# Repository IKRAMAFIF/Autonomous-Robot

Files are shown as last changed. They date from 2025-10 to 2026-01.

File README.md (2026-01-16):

# 🤖 Projet CATRONIC : Robot Autonome "Chat et Souris"

<p align="center">
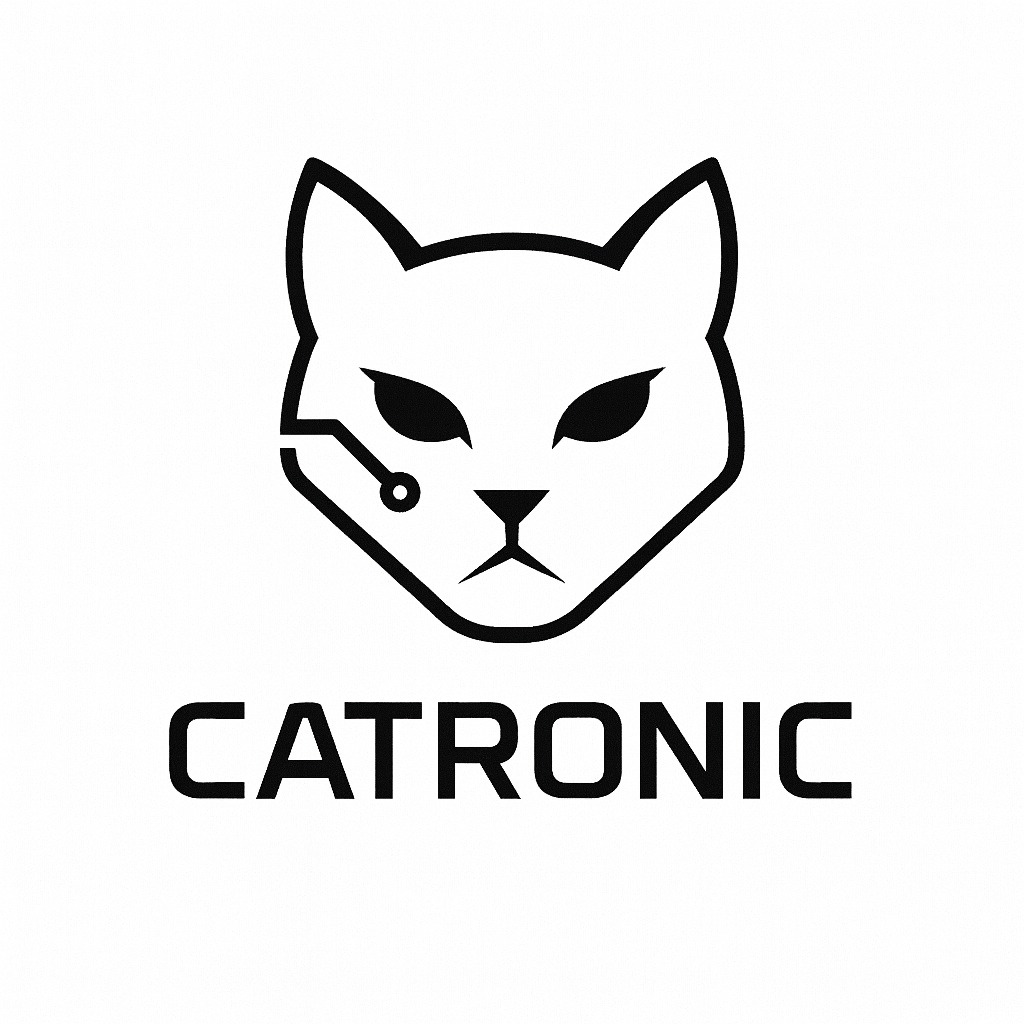
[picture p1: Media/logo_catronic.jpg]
Logo Catronic
  
</p>

> **Auteurs :** AFIF Ikram, AIT ALLA Hajar, MENJLI Fakhri

> **Encadré par :** Laurent FIACK, Nicolas PAPAZOGLOU

> **Année académique :** 2025/2026

Le robot **CATRONIC** est un système embarqué autonome conçu pour simuler un jeu de chat et de souris entre plusieurs robots identiques. Les robots évoluent sur une table sans bordures et sont capables de détecter les bords pour éviter toute chute.

---

##  Table des matières
- [Stratégie de fonctionnement](#stratégie-de-fonctionnement)
- [Architecture du système](#architecture-du-système-global)
  - [Schémas généraux](#schémas-généraux)
  - [Sous-systèmes](#sous-systèmes)
- [Nomenclature (Bill of Materials)](#nomenclature-bill-of-materials)
- [Structure logicielle et FreeRTOS](#structure-logicielle-et-freertos)
- [Tests et validation](#tests-et-validation)
- [Test final](#test-final)
- [Conclusion](#conclusion)

---

##  Stratégie de fonctionnement

La logique du robot est orchestrée par un noyau temps réel (**FreeRTOS**), permettant de gérer plusieurs tâches simultanément pour une réactivité maximale.

### Détection de l'environnement

- **Détection des bords :** Le robot utilise des **capteurs mécaniques Würth WS-MITV** positionnés à l’avant, à l’arrière, à gauche et à droite. Lorsqu’un capteur détecte le vide, il déclenche une interruption qui ordonne un changement immédiat de direction pour éviter la chute.  
- **Détection des adversaires :** Le **LIDAR YDLIDAR X2** scanne l’environnement à 360° et transmet en temps réel la position et la distance des autres robots.  
- **Détection des collisions :** L’**accéléromètre ADXL343** détecte les chocs par variation brutale d’accélération. Il est également utilisé comme arrêt d’urgence manuel.

### Modes de jeu

- **Mode Souris 🐭 :** Le robot cherche à maximiser la distance avec le “chat” tout en évitant les bords de la table.  
- **Mode Chat 🐱 :** Le robot identifie la “souris” la plus proche via le LIDAR et cherche à la percuter.

---

##  Architecture du système global

L’architecture est organisée autour de cinq sous-ensembles principaux : **alimentation**, **commande**, **acquisition**, **déplacement** et **interface utilisateur**.

### Schémas généraux

Vues d’ensemble de l’architecture matérielle :

**Figure 1 – Diagramme d’architecture fonctionnelle du robot:**

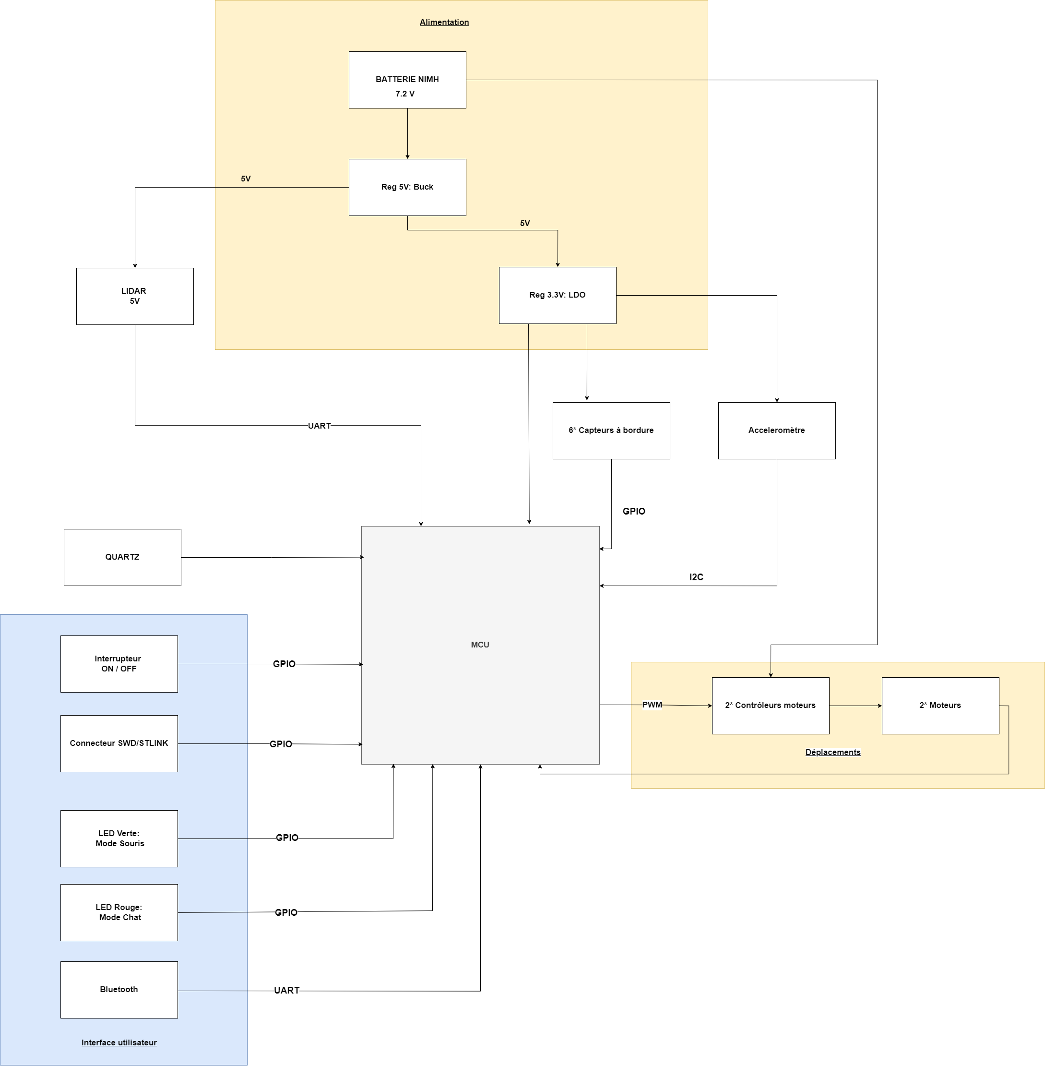
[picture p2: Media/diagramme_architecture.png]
Diagramme d'architecture


**Figure 2 – Schéma global du système:**

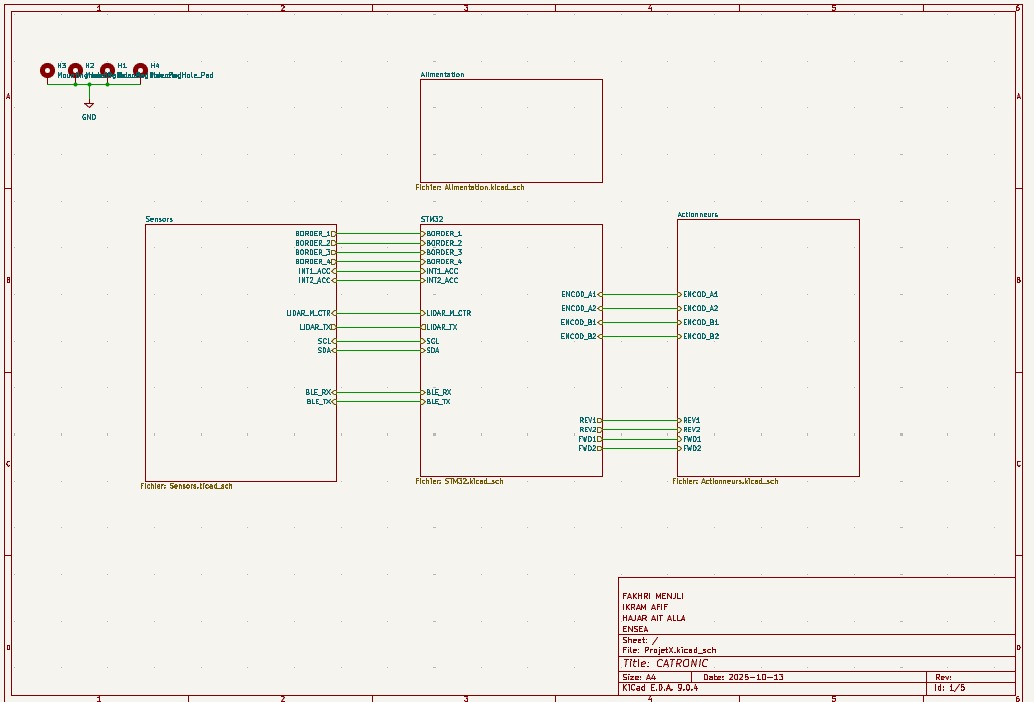
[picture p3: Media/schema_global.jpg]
Schéma global


**Figure 3 – Routage du PCB principal:**

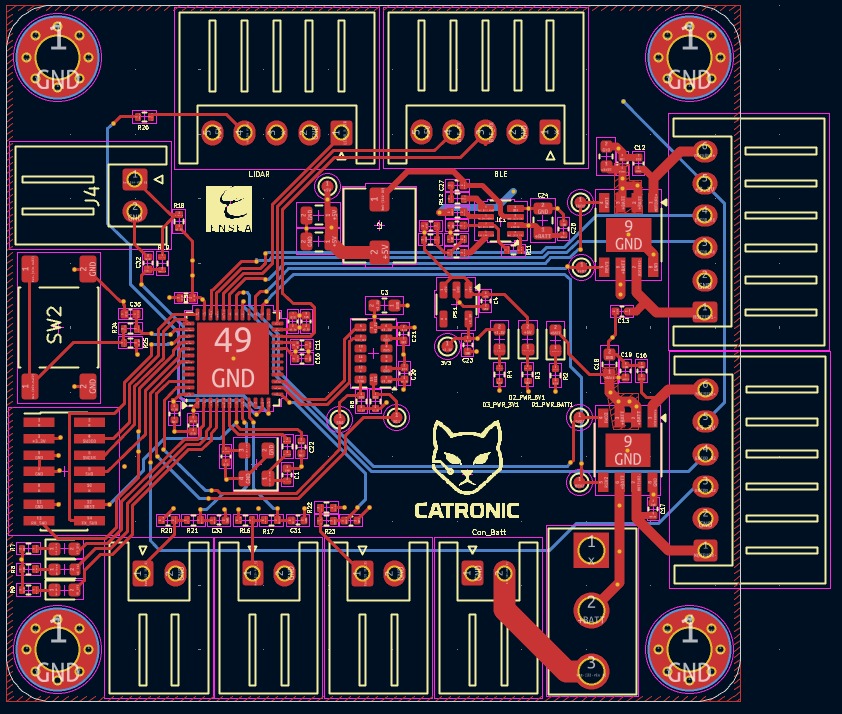
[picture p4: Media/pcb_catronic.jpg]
PCB Catronic


**Figure 4 – Vue 3D du PCB sous KiCad:**

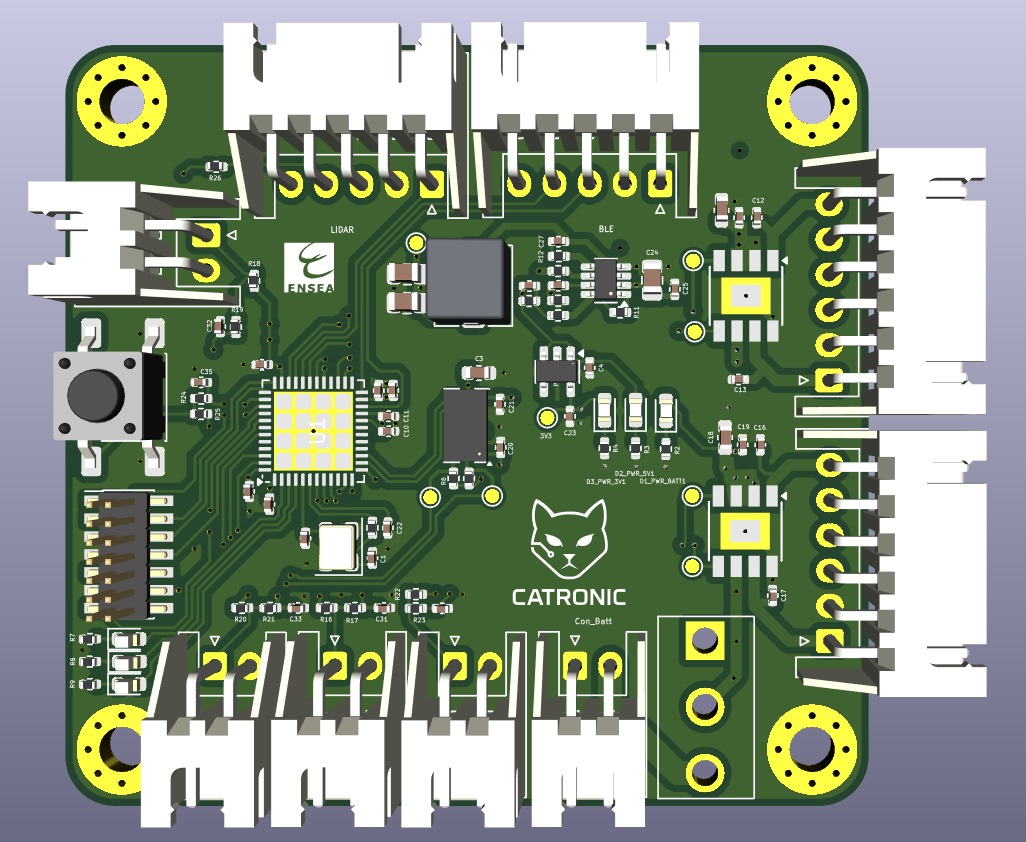
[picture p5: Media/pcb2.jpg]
Vue 3D du PCB


### Sous-systèmes

####  Alimentation
Le robot est alimenté par une batterie **NiMH 7.2V**, régulée en **5V** pour le LIDAR et en **3.3V** pour le reste des composants.

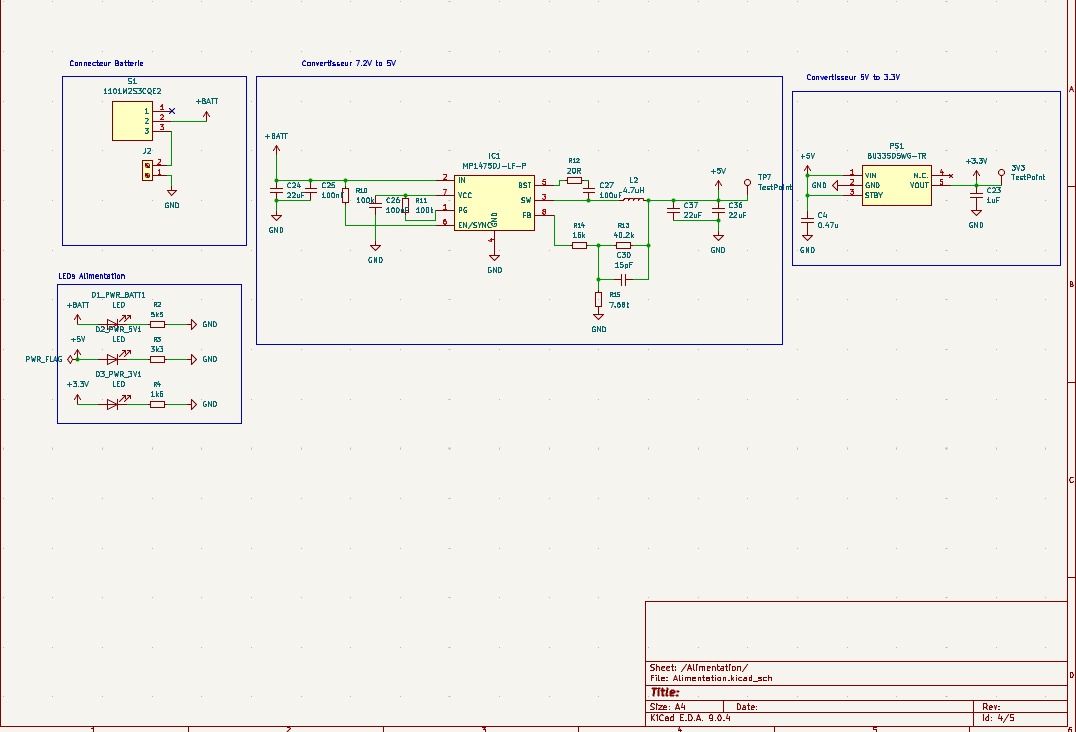
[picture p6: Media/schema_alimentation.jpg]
Schéma d'alimentation

*Figure 5 – Schéma d’alimentation du robot.*

####  Commande
Le cœur du système repose sur un **STM32G431CBU6** (ARM Cortex-M4) exécutant **FreeRTOS** pour coordonner les différentes tâches.

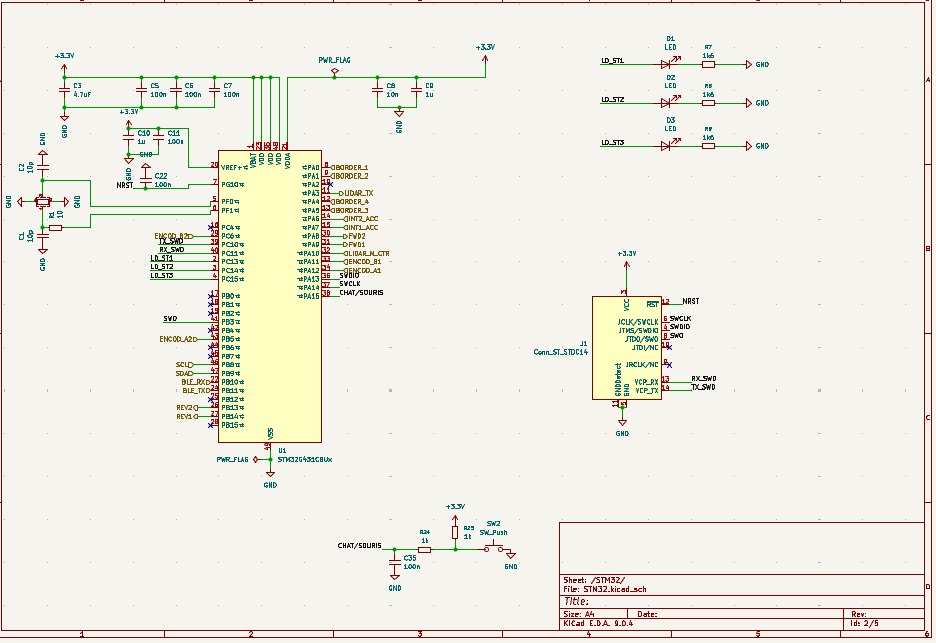
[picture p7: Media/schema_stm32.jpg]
Schéma STM32


*Figure 6 – Schéma de la carte de commande STM32.*

#### Acquisition
Ce sous-système regroupe les capteurs assurant la perception de l’environnement.

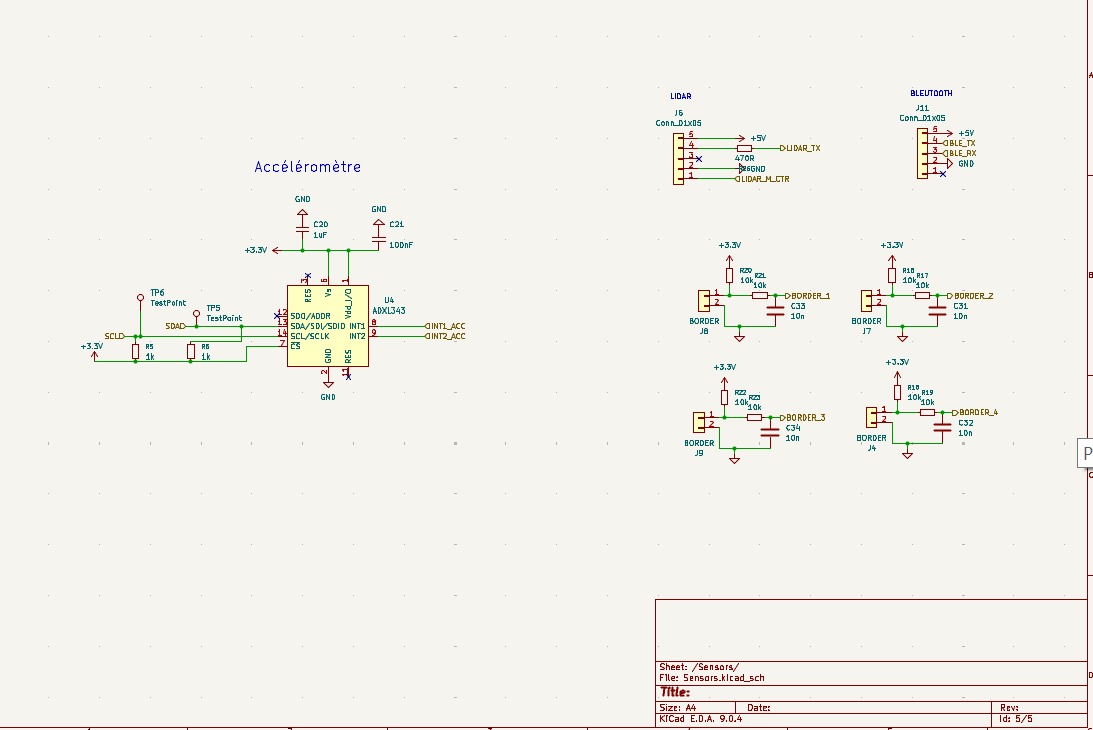
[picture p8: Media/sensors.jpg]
Schéma des capteurs (sensors)


*Figure 7 – Sous-système de détection (LIDAR, accéléromètre, capteurs WS-MITV).* 

####  Déplacement
Deux moteurs DC, commandés par des **drivers ZXBM5210-SP-13**, permettent un contrôle précis de la vitesse et de la direction via des signaux PWM.

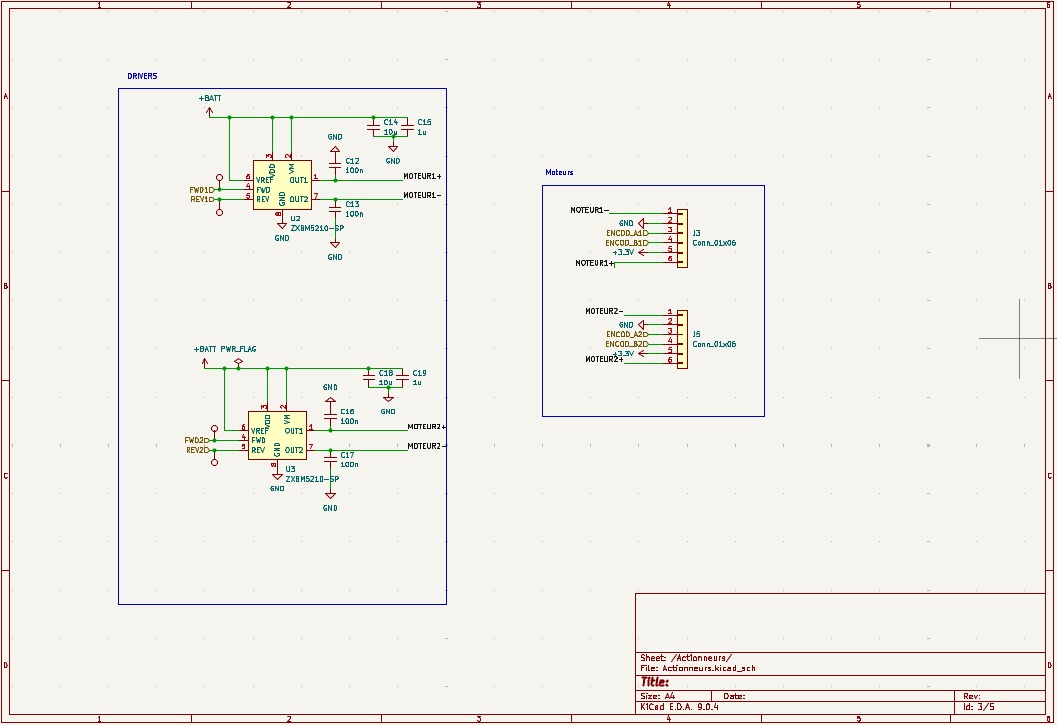
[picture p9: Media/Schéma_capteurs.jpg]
Schéma des actionneurs


*Figure 8 – Schéma des moteurs et drivers.*

####  Interface utilisateur
Interrupteur, bouton de démarrage, LED de statut et connecteur SWD pour le débogage.

---

##  Nomenclature (Bill of Materials)

| Composant | Référence | Datasheet |
|:---|:---|:---|
| Microcontrôleur | STM32G431CBU6 | [Datasheet](https://www.st.com/resource/en/datasheet/stm32g431c6.pdf) |
| Driver moteur | ZXBM5210-SP-13 | [Datasheet](https://www.mouser.fr/datasheet/3/175/1/ZXBM5210.pdf) |
| Accéléromètre | ADXL343BCCZ-RL | [Datasheet](https://www.analog.com/media/en/technical-documentation/data-sheets/adxl343.pdf) |
| LIDAR | YDLIDAR X2 | [Datasheet](https://cdn.robotshop.com/media/y/ydl/rb-ydl-04/pdf/ydlidar-x2-360-laser-scanner-datasheet2.pdf) |
| Régulateur 5V | MP1475DJ-LF-P | [Datasheet](https://www.farnell.com/datasheets/2915024.pdf) |
| Régulateur 3.3V | BU33SD5WG-TR | [Datasheet](https://fscdn.rohm.com/en/products/databook/datasheet/ic/power/linear_regulator/buxxsd5wg-e.pdf) |
| Batterie | NiMH 7.2V 1.3Ah | [Datasheet](https://fr.rs-online.com/web/p/blocs-batteries-rechargeables/7770377) |
| Capteur bordure | WS-MITV THT | [Datasheet](https://www.we-online.com/en/components/products/MITV_12_8X5_8_THT__LEVER_LEFT_55GF) |
| Bluetooth | HC-05 | [Datasheet](https://components101.com/sites/default/files/component_datasheet/HC-05%20Datasheet.pdf) |
| Boutons poussoirs | Wurth 430182070816 | [Datasheet](https://www.we-online.com/components/products/datasheet/430182070816.pdf) |
| Interrupteur ON/OFF | Wurth 472121020311 | [Datasheet](https://www.we-online.com/components/products/datasheet/472121020311.pdf) |

---
## Fichiers sources principaux

-   **`main.c`** : Point d'entrée du programme. Ce fichier initialise le microcontrôleur, tous les périphériques (GPIO, I2C, UART, Timers), les pilotes (moteurs, LIDAR), et crée les quatre tâches FreeRTOS qui orchestrent le comportement du robot.
-   **`robot_logic.c`** : Cœur de l'intelligence du robot. Il contient l'implémentation des tâches FreeRTOS qui gèrent la logique de jeu, la détection des collisions et des bordures, ainsi que la communication.
-   **`MoteurPWM.c`** : Pilote pour le contrôle des moteurs DC. Il fournit des fonctions pour initialiser les moteurs, et contrôler leur vitesse via des signaux PWM.
-   **`ADXL343_driver.c`** : Pilote pour l'accéléromètre ADXL343. Il gère l'initialisation du capteur et la détection de chocs.
-   **`driver_LIDAR.c`** : Pilote pour le capteur LIDAR YDLIDAR X2. Il traite les données brutes reçues via UART DMA pour en extraire la distance et l'angle des obstacles.
-   **`border_sensors.c`** : Gère la logique des capteurs de bordure.
-   **`drv_bt.c`** : Assure la gestion de la communication Bluetooth (HC-05), notamment la réception de commandes.

##  Structure logicielle et FreeRTOS

Le comportement du robot est géré par **quatre tâches FreeRTOS** principales :

1.  **`BorderTask`**
    -   **Rôle :** Surveille en permanence les capteurs de bordure.
    -   **Fonctionnement :** À intervalle régulier (100 ms), la tâche lit l'état des capteurs. Si un bord est détecté, elle met à jour une variable globale (`border_active`) protégée par un mutex pour signaler l'état et la direction du bord détecté à la tâche principale `RobotModeTask`.

2.  **`ShockTask`**
    -   **Rôle :** Détecte les collisions et inverse les rôles "Chat" et "Souris".
    -   **Fonctionnement :** La tâche initialise l'accéléromètre pour la détection de chocs. Elle vérifie en continu si un choc a eu lieu. Si c'est le cas, elle change l'état du robot (`robot_mode`) de `CHAT` à `SOURIS` ou inversement.

3.  **`BluetoothTask`**
    -   **Rôle :** Traite les commandes reçues via Bluetooth.
    -   **Fonctionnement :** La tâche attend de recevoir des commandes utilisateur. Elle peut ainsi forcer le robot à s'arrêter (`STOP`), à démarrer (`START`), ou à passer en mode `CHAT` ou `SOURIS`, offrant un contrôle manuel sur le comportement du robot.

4.  **`RobotModeTask`**
    -   **Rôle :** Tâche principale qui exécute la logique de déplacement et de jeu.
    -   **Fonctionnement :** C'est la tâche la plus complexe. À chaque cycle :
        -   Elle vérifie l'état de la variable `border_active`. Si un bord est détecté, elle exécute une manœuvre d'évitement prioritaire (reculer puis tourner) pour empêcher le robot de tomber.
        -   Si aucun bord n'est détecté, elle exécute la logique de jeu en fonction de la variable `robot_mode` :
            -   **Mode `ROBOT_STOP` :** Les moteurs sont à l'arrêt.
            -   **Mode `ROBOT_MODE_CHAT` (Poursuite) :** La tâche analyse les données du LIDAR pour trouver l'obstacle le plus proche. Si l'obstacle est en face, elle commande au robot d'avancer. Sinon, elle le fait tourner pour se diriger vers la cible.
            -   **Mode `ROBOT_MODE_SOURIS` (Fuite) :** Si un obstacle (le "chat") est détecté à moins de 30 cm, le robot recule pour s'en éloigner. Sinon, il continue d'avancer pour explorer la zone de jeu.
        -   Si aucun obstacle n'est détecté par le LIDAR, le robot s'arrête.

---

##  Tests et validation

Pour garantir la fiabilité du système, plusieurs séries de tests ont été menées.

### Test de déplacement et moteurs

Ce test valide le contrôle PWM et met en évidence les écarts de vitesse entre les moteurs. 
Un ajustement asymétrique des vitesses a permis d’améliorer la précision du déplacement du robot.

<p align="center">
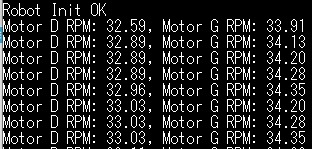
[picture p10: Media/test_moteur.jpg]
  
</p>

### Test de détection de bordures/détection de collision

Ce test est crucial pour la sécurité du robot. Il valide la robustesse des capteurs mécaniques, et la détection des chocs via l'accéléromètre qui déclenche le changement de rôle du robot
- **Approche frontale :** Le robot est dirigé droit vers le bord de la table. On vérifie qu'il s'arrête et recule à chaque fois, sans chute.
- **Approche en diagonale :** Le test est répété avec différents angles d'approche pour s'assurer que le levier du capteur est bien actionné même lorsque le robot n'est pas perpendiculaire au bord.
- **Fiabilité :** Répétition du test des dizaines de fois pour garantir la reproductibilité et la fiabilité du mécanisme.
- **Changement de mode après impact :** Après une collision détectée par l'accéléromètre, on vérifie que les rôles "Chat" et "Souris" sont bien inversés.

<p align="center">
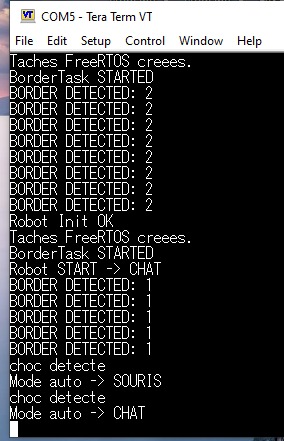
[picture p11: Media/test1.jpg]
  
</p>

*Figure 9 – Détection de bordures/chocs et changement de direction.*

### Test du LIDAR et logique de jeu

Ce test valide la perception de l'environnement et la stratégie comportementale.
- **Fiabilité de la détection d'adversaire :** Vérification que le LIDAR détecte de manière fiable la position de l'autre robot.
- **Logique de poursuite/fuite :** Validation de la trajectoire du robot en fonction des données du LIDAR (le "Chat" se rapproche de la "Souris", et la "Souris" s'en éloigne).

<p align="center">
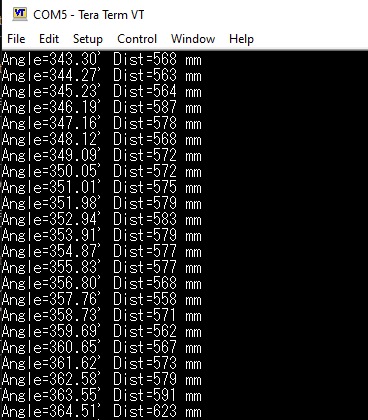
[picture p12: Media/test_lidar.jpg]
  
</p>

*Figure 10 – Données LIDAR capturées via Tera Term (UART DMA).* 

### Test Bluetooth

Ce test vérifie la connectivité et la fiabilité de la communication sans fil via le module Bluetooth HC-05.

- **Connexion :** Vérification de l'établissement de la connexion Bluetooth avec un appareil externe.

- **Transmission de données :** Test de l'envoi et de la réception de données entre le robot et l'appareil connecté.

- **Changement de mode à distance :** Validation de la capacité à modifier le rôle du robot (Chat/Souris) via une commande Bluetooth.

<p align="center">
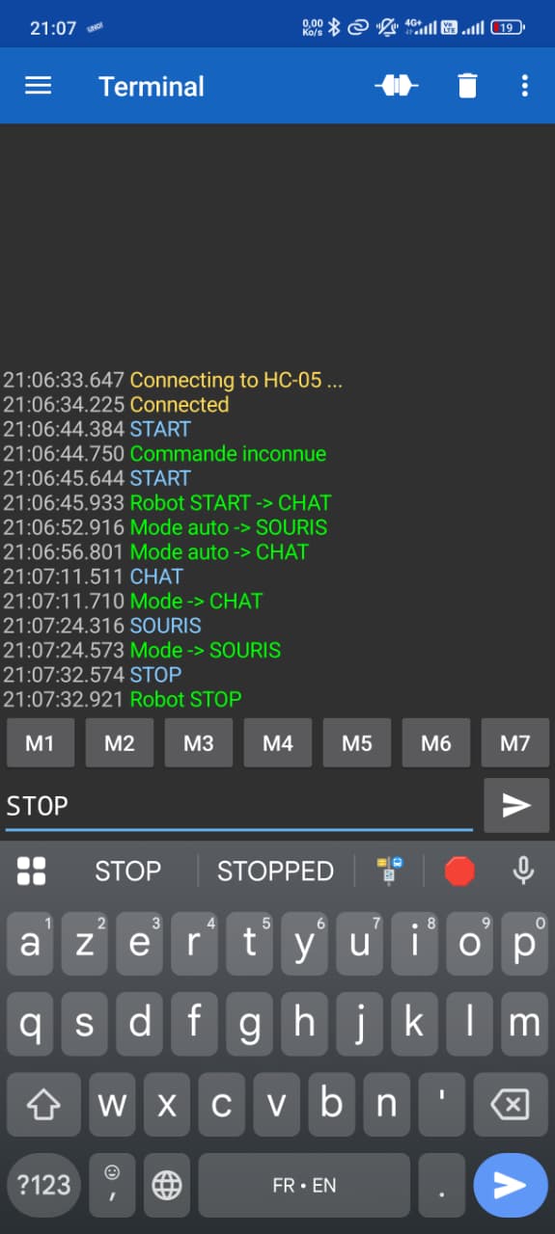
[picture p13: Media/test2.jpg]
  
</p>

*Figure 11 – Communication Bluetooth et affichage des données.*

---
## Structure du dépôt GitHub

```
├── Firmware/           → Code STM32CubeIDE 
├── Hardware/           → Schémas, PCB et vues 3D KiCad
├── Media/              → Illustrations et résultats de tests
└── README.md           → Présentation du projet
```

---
##  Test final

<p align="center">
  
</p>

Lors du test final, le robot a validé plusieurs fonctionnalités clés. Les capteurs de bordure fonctionnent correctement, permettant au robot de détecter les limites de la surface et d’éviter toute chute. La commande via Bluetooth est également opérationnelle : il est possible de sélectionner le mode de fonctionnement du robot ainsi que d’envoyer des commandes Start et Stop pour lancer ou arrêter le système. Les données du LiDAR ont pu être lues avec succès, cependant toutes les mesures n’étaient pas fiables et l’intégration complète du capteur dans le système embarqué n’a pas pu être finalisée. En conséquence, le robot n’est pas capable de détecter les autres robots à ce stade. Enfin, l’accéléromètre permet de détecter les chocs lors d’une collision, déclenchant automatiquement un changement de mode de fonctionnement du robot.

---
## Conclusion

Ce projet a permis de concevoir et de mettre en œuvre un robot mobile intégrant plusieurs capteurs et modes de fonctionnement. Les tests finaux ont validé avec succès la détection des bordures, la commande via Bluetooth avec sélection des modes ainsi que la gestion des collisions à l’aide de l’accéléromètre. Ces fonctionnalités assurent un fonctionnement sûr et contrôlable du robot.

Cependant, certains défis techniques ont été rencontrés, notamment lors de l’exploitation et de l’intégration du LiDAR. Bien que les données aient pu être lues, leur fiabilité et leur intégration complète dans l’architecture embarquée n’ont pas pu être finalisées, empêchant la détection des autres robots. Ces limitations sont principalement liées aux contraintes de temps et à la complexité du traitement des données capteur.

Ce travail a néanmoins permis d’acquérir une expérience pratique solide en systèmes embarqués, en communication sans fil et en intégration capteurs. Des perspectives d’amélioration incluent l’optimisation du traitement des données LiDAR, l’amélioration de la fusion capteurs et l’extension des capacités de détection du robot.

---

<p align="center">
  2026 — Projet académique ENSEA
  <br>Développement d’un robot autonome Chat–Souris 
</p>

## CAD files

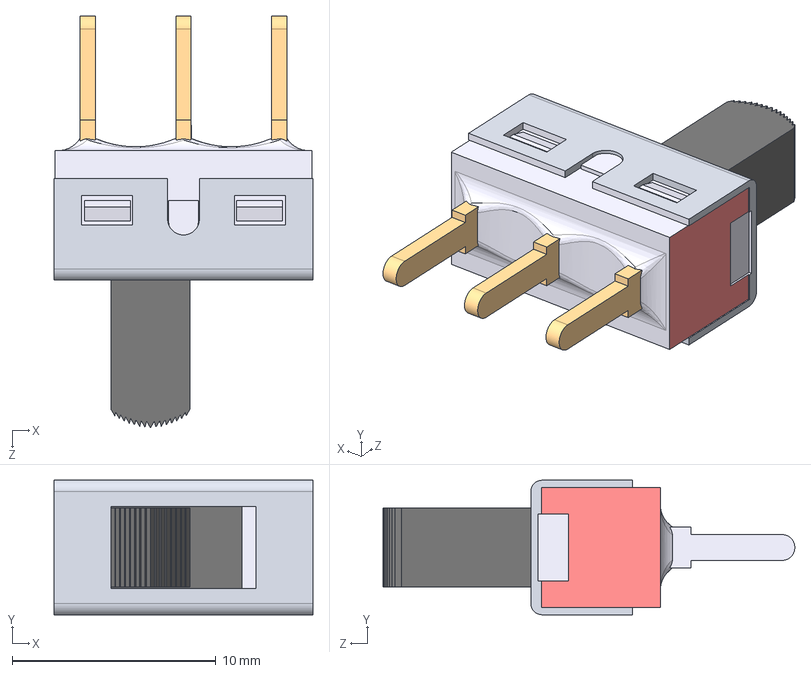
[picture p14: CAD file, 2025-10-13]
Hardware/FootPrint/1101M2S3CQE2/1101M2S3CQE2/3D/1101M2S3CQE2.stp
12.7 x 6.60 x 20.2 mm

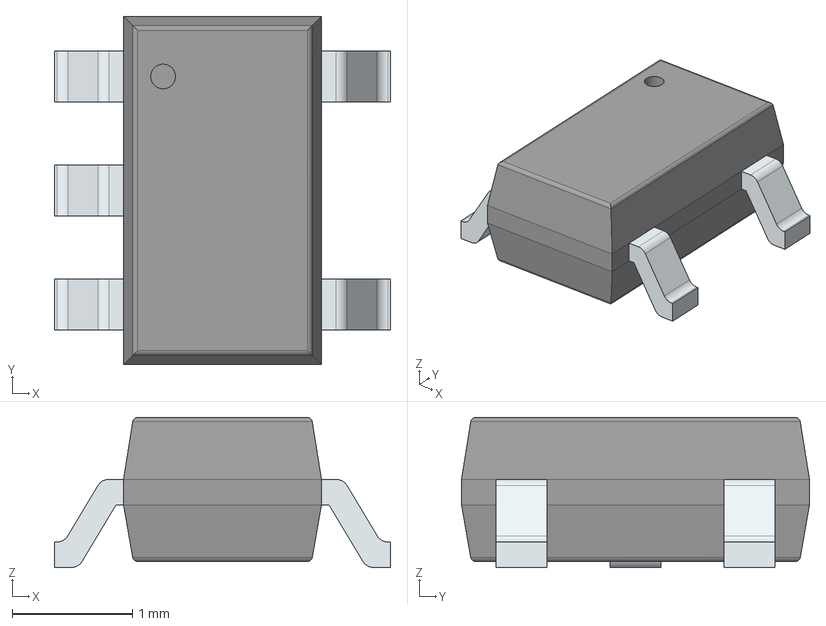
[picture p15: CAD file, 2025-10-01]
Hardware/FootPrint/LIB_BU33SD5WG-TR/BU33SD5WG-TR/3D/BU33SD5WG-TR.stp
2.80 x 2.90 x 1.25 mm
PinsArrayL
PinsArrayR

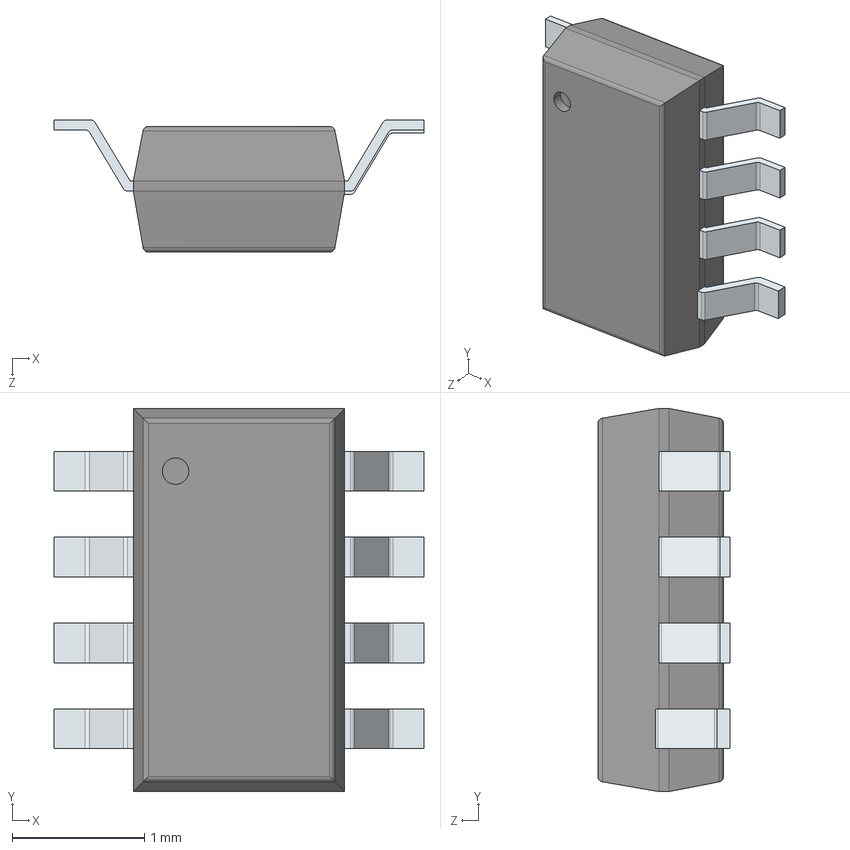
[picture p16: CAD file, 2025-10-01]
Hardware/FootPrint/MP1475DJ-LF-P/3D/MP1475DJ-LF-P.stp
2.80 x 2.90 x 1.00 mm
PinsArrayLR_2
PinsArrayLR_5
PinsArrayLR_1
PinsArrayLR
PinsArrayLR_6
PinsArrayLR_7
PinsArrayLR_3
PinsArrayLR_4

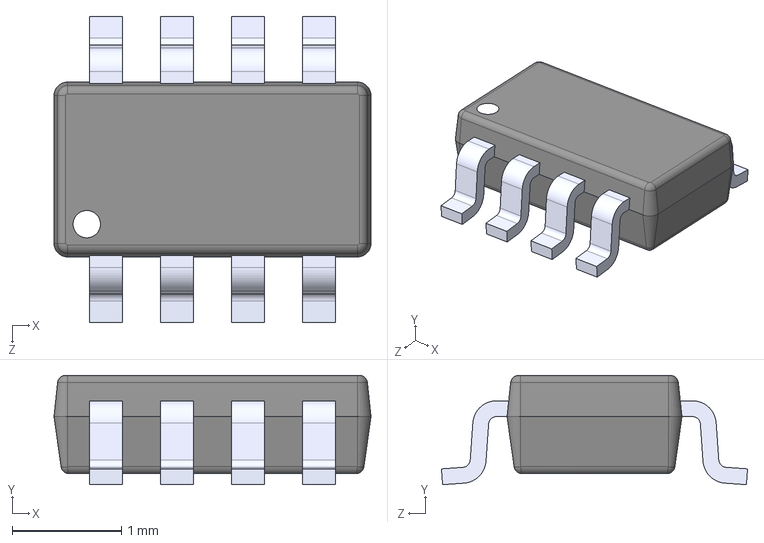
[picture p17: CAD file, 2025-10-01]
Hardware/FootPrint/MP1495/MP1495.step
2.90 x 1.00 x 2.80 mm

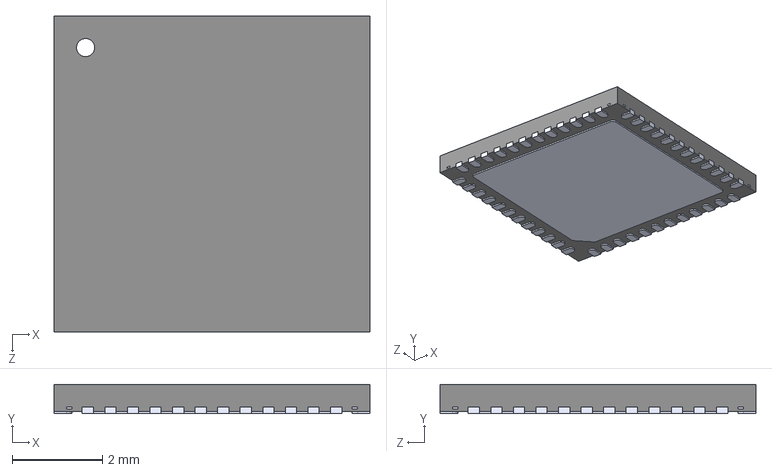
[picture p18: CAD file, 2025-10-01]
Hardware/FootPrint/STM32/STM32G431CBU6.STEP
7.00 x 0.65 x 7.00 mm

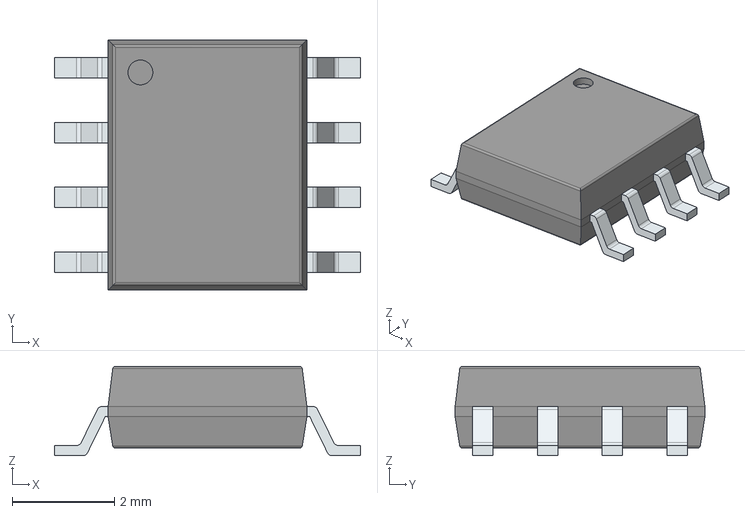
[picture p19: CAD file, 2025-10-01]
Hardware/FootPrint/ZXBM5210/ZXBM5210-S-13.stp
6.00 x 4.90 x 1.75 mm
PinsArrayLR

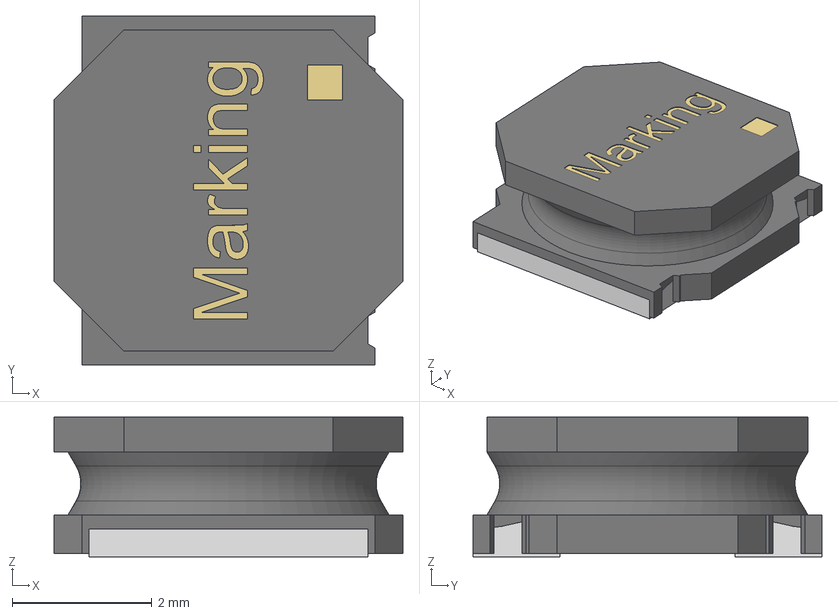
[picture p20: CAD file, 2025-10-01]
Hardware/FootPrint/Inductance/74404052010_Download_STP_WE-LQS-5020_rev1.stp
5.00 x 5.00 x 2.00 mm
housing
contact x 2
Glue

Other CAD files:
Hardware/FootPrint/1101M2S3CQE2/1101M2S3CQE2/Allegro/1000-series_spdt_.psm
Hardware/FootPrint/1101M2S3CQE2/1101M2S3CQE2/DEHDL/1101m2s3cqe2/chips/chips.prt
Hardware/FootPrint/LIB_BU33SD5WG-TR/BU33SD5WG-TR/Allegro/sot95p280x125-5n.psm
Hardware/FootPrint/LIB_BU33SD5WG-TR/BU33SD5WG-TR/DEHDL/bu33sd5wg_tr/chips/chips.prt
Hardware/FootPrint/MP1475DJ-LF-P/Allegro/sot65p280x100-8n.psm
Hardware/FootPrint/MP1475DJ-LF-P/DEHDL/mp1475dj_lf_p/chips/chips.prt
Hardware/FootPrint/sw/1101M2S3CQE2/Allegro/1000-series_spdt_.psm
Hardware/FootPrint/sw/1101M2S3CQE2/DEHDL/1101m2s3cqe2/chips/chips.prt
Hardware/FootPrint/sw1/1101M2S3CQE2/Allegro/1000-series_spdt_.psm
Hardware/FootPrint/sw1/1101M2S3CQE2/DEHDL/1101m2s3cqe2/chips/chips.prt

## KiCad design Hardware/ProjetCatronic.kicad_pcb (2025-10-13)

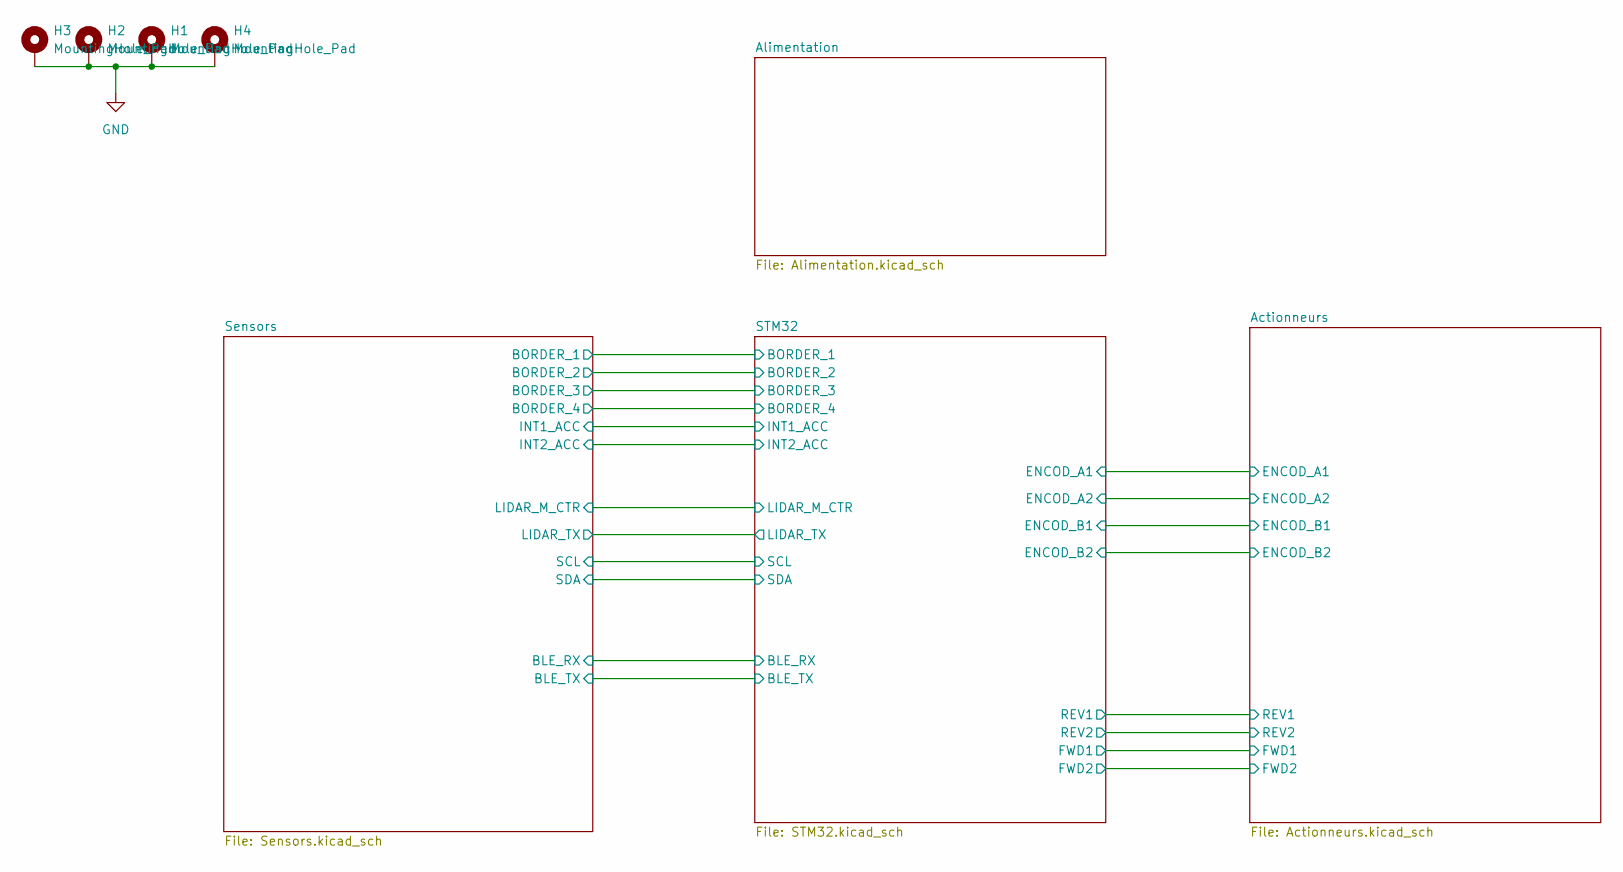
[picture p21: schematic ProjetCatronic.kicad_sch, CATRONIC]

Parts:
H1, H2, H3, H4: MountingHole_Pad; MountingHole_3.2mm_M3_Pad_Via

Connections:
GND: H1.1, H2.1, H3.1, H4.1; also elsewhere on the board

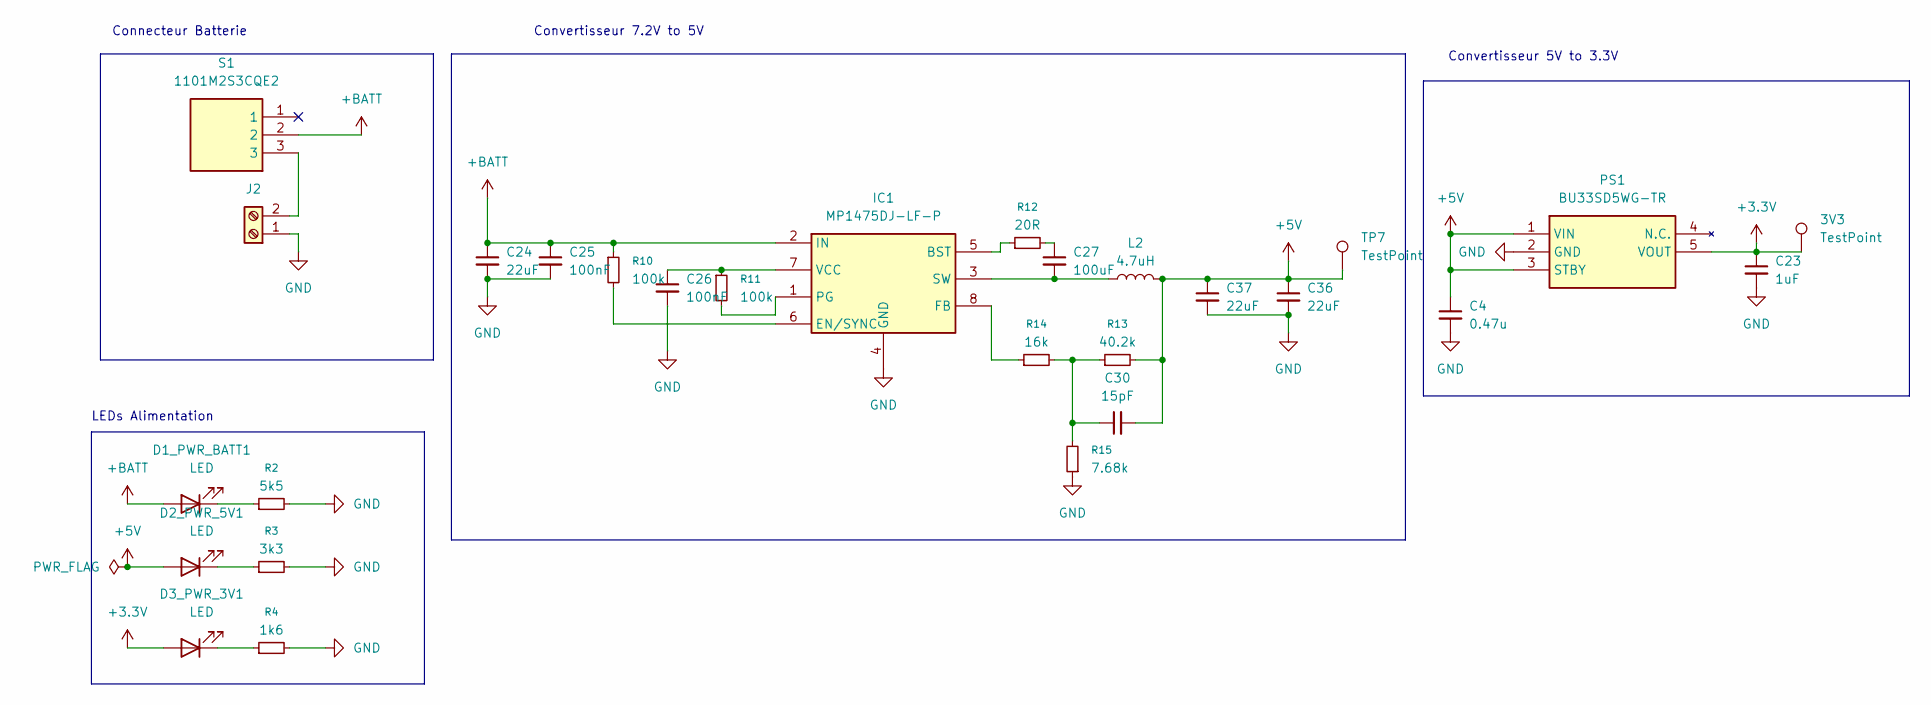
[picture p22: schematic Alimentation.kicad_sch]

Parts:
3V3: TestPoint; TestPoint_Pad_D1.0mm
C4: 0.47u; C_0402_1005Metric
C23: 1uF; C_0402_1005Metric
C24, C36, C37: 22uF; C_0805_2012Metric
C25, C26: 100nF; C_0402_1005Metric
C27: 100uF; C_0402_1005Metric
C30: 15pF; C_0402_1005Metric
D1_PWR_BATT1: LED; LED_0603_1608Metric; MPN 150060GS55040
D2_PWR_5V1: LED; LED_0603_1608Metric; MPN 150060BS55040
D3_PWR_3V1: LED; LED_0603_1608Metric; MPN 150060RS55040
IC1: MP1475DJ-LF-P; TSOT-23-8; Manufacturer_Part_Number MP1475DJ-LF-P
J2: Screw_Terminal_01x02; JST_XH_S2B-XH-A_1x02_P2.50mm_Horizontal
L2: 4.7uH; L_Wuerth_HCI-5040
PS1: BU33SD5WG-TR; TSOT-23-5; Manufacturer_Part_Number BU33SD5WG-TR
R2: 5k5; R_0402_1005Metric
R3: 3k3; R_0402_1005Metric
R4: 1k6; R_0402_1005Metric
R10, R11: 100k; R_0402_1005Metric
R12: 20R; R_0402_1005Metric
R13: 40.2k; R_0402_1005Metric
R14: 16k; R_0402_1005Metric
R15: 7.68k; R_0402_1005Metric
S1: 1101M2S3CQE2; sw wurth; Mouser Part Number 611-1101M2S3CQE2
TP7: TestPoint; TestPoint_Pad_D1.0mm

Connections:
+3.3V: 3V3.1, C23.1, D3_PWR_3V1.2 (A), PS1.5 (VOUT); also elsewhere on the board
+5V: C4.1, C30.2, C36.1, C37.1, D2_PWR_5V1.2 (A), L2.2, PS1.1 (VIN), PS1.3 (STBY), R13.2, TP7.1; also elsewhere on the board
+BATT: C24.1, C25.1, D1_PWR_BATT1.2 (A), IC1.2 (IN), R10.1, S1.2; also elsewhere on the board
GND: C4.2, C23.2, C24.2, C25.2, C26.2, C36.2, C37.2, IC1.4 (GND), J2.1, PS1.2 (GND), R2.2, R3.2, R4.2, R15.1; also elsewhere on the board
unnamed: C27.1, R12.2
unnamed: C30.1, R13.1, R14.2, R15.2
unnamed: D1_PWR_BATT1.1 (K), R2.1
unnamed: D2_PWR_5V1.1 (K), R3.1
unnamed: D3_PWR_3V1.1 (K), R4.1
unnamed: IC1.5 (BST), R12.1
unnamed: IC1.6 (EN/SYNC), R10.2
unnamed: IC1.8 (FB), R14.1
unnamed: IC1.1 (PG), R11.2
unnamed: C27.2, IC1.3 (SW), L2.1
unnamed: C26.1, IC1.7 (VCC), R11.1
unnamed: J2.2, S1.3

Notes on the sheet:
Convertisseur 7.2V to 5V
Connecteur Batterie
Convertisseur 5V to 3.3V
LEDs Alimentation

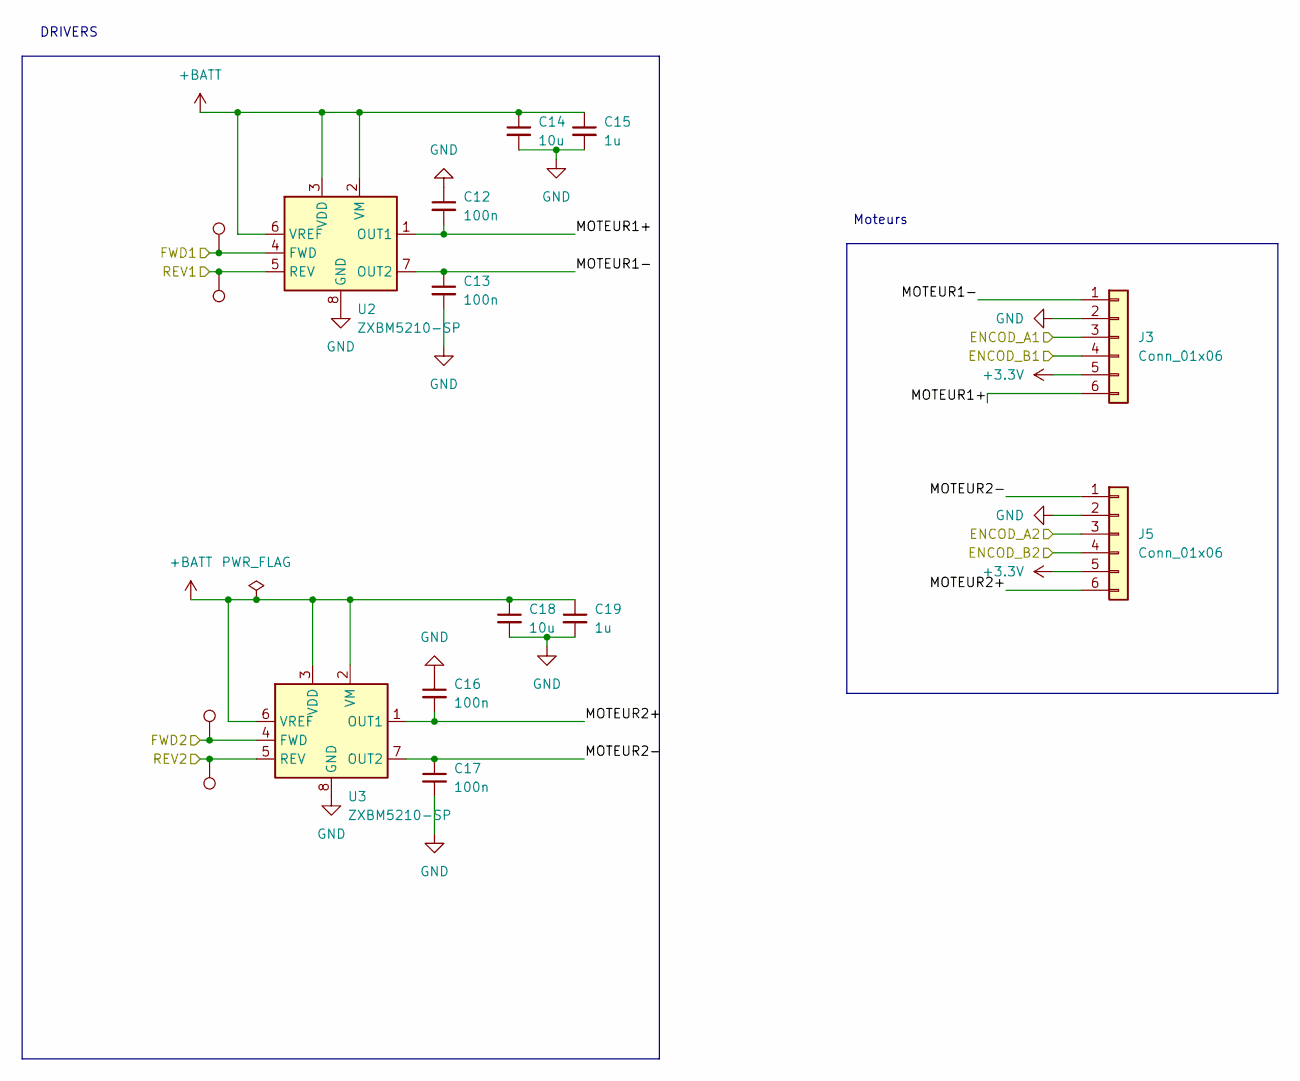
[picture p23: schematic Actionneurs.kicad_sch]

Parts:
C12, C13, C16, C17: 100n; C_0402_1005Metric
C14, C18: 10u; C_0603_1608Metric
C15, C19: 1u; C_0402_1005Metric
J3, J5: Conn_01x06; JST_XH_S6B-XH-A_1x06_P2.50mm_Horizontal; MPN DfRobot FIT0521
TP1, TP2, TP3, TP4: TestPoint; TestPoint_Pad_D1.0mm
U2, U3: ZXBM5210-SP; Diodes_SO-8EP; MPN ZXBM5210-SP

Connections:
+3.3V: J3.5, J5.5; also elsewhere on the board
+BATT: C14.1, C15.1, C18.1, C19.1, U2.2 (VM), U2.3 (VDD), U2.6 (VREF), U3.2 (VM), U3.3 (VDD), U3.6 (VREF); also elsewhere on the board
/Actionneurs/ENCOD_A1: J3.3; also elsewhere on the board
/Actionneurs/ENCOD_A2: J5.3; also elsewhere on the board
/Actionneurs/ENCOD_B1: J3.4; also elsewhere on the board
/Actionneurs/ENCOD_B2: J5.4; also elsewhere on the board
/Actionneurs/FWD1: TP1.1, U2.4 (FWD); also elsewhere on the board
/Actionneurs/FWD2: TP3.1, U3.4 (FWD); also elsewhere on the board
/Actionneurs/MOTEUR1+: C12.2, J3.6, U2.1 (OUT1)
/Actionneurs/MOTEUR1-: C13.1, J3.1, U2.7 (OUT2)
/Actionneurs/MOTEUR2+: C16.2, J5.6, U3.1 (OUT1)
/Actionneurs/MOTEUR2-: C17.1, J5.1, U3.7 (OUT2)
/Actionneurs/REV1: TP2.1, U2.5 (REV); also elsewhere on the board
/Actionneurs/REV2: TP4.1, U3.5 (REV); also elsewhere on the board
GND: C12.1, C13.2, C14.2, C15.2, C16.1, C17.2, C18.2, C19.2, J3.2, J5.2, U2.8 (GND), U2.9 (GND), U3.8 (GND), U3.9 (GND); also elsewhere on the board

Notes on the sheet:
DRIVERS
Moteurs

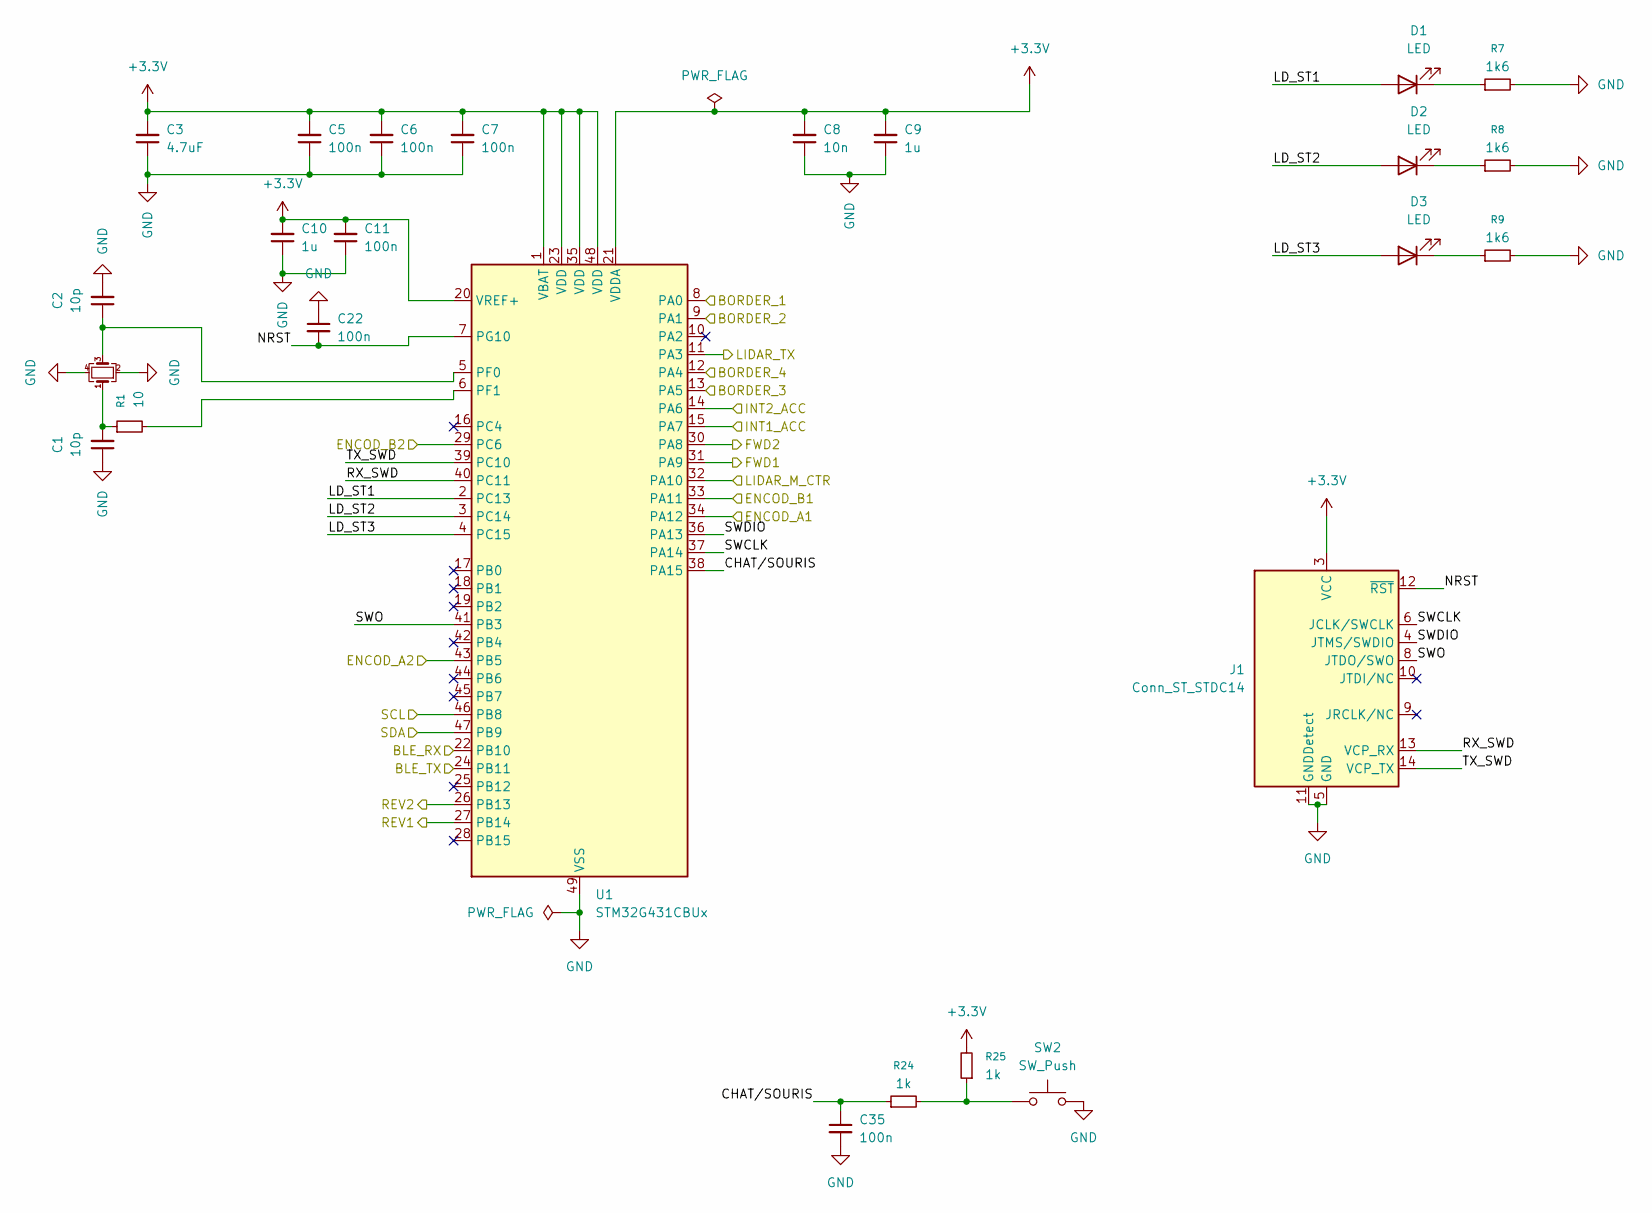
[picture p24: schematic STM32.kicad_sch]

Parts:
C1, C2: 10p; C_0402_1005Metric
C3: 4.7uF; C_0603_1608Metric
C5, C6, C7, C11, C22, C35: 100n; C_0402_1005Metric
C8: 10n; C_0402_1005Metric
C9, C10: 1u; C_0402_1005Metric
D1, D2, D3: LED; LED_0603_1608Metric; MPN 150060RS55040
J1: Conn_ST_STDC14; PinHeader_2x07_P1.27mm_Vertical_SMD; MPN SAMTEC FTSH-107-01-L-DV-K-A.
R1: 10; R_0402_1005Metric
R7, R8, R9: 1k6; R_0402_1005Metric
R24, R25: 1k; R_0402_1005Metric
SW2: SW_Push; SW_Push_1P1T_NO_E-Switch_TL3301NxxxxxG
U1: STM32G431CBUx; QFN-48-1EP_7x7mm_P0.5mm_EP5.6x5.6mm; MPN STM32G4316B
Y1: Crystal_GND24_Small; Crystal_SMD_EuroQuartz_MT-4Pin_3.2x2.5mm

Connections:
+3.3V: C3.2, C5.2, C6.2, C7.2, C8.2, C9.2, C10.2, C11.2, J1.3 (VCC), R25.2, U1.1 (VBAT), U1.20 (VREF+), U1.21 (VDDA), U1.23 (VDD), U1.35 (VDD), U1.48 (VDD); also elsewhere on the board
/Actionneurs/ENCOD_A1: U1.34 (PA12); also elsewhere on the board
/Actionneurs/ENCOD_A2: U1.43 (PB5); also elsewhere on the board
/Actionneurs/ENCOD_B1: U1.33 (PA11); also elsewhere on the board
/Actionneurs/ENCOD_B2: U1.29 (PC6); also elsewhere on the board
/Actionneurs/FWD1: U1.31 (PA9); also elsewhere on the board
/Actionneurs/FWD2: U1.30 (PA8); also elsewhere on the board
/Actionneurs/REV1: U1.27 (PB14); also elsewhere on the board
/Actionneurs/REV2: U1.26 (PB13); also elsewhere on the board
/STM32/BLE_RX: U1.22 (PB10); also elsewhere on the board
/STM32/BLE_TX: U1.24 (PB11); also elsewhere on the board
/STM32/BORDER_1: U1.8 (PA0); also elsewhere on the board
/STM32/BORDER_2: U1.9 (PA1); also elsewhere on the board
/STM32/BORDER_3: U1.13 (PA5); also elsewhere on the board
/STM32/BORDER_4: U1.12 (PA4); also elsewhere on the board
/STM32/CHAT/SOURIS: C35.1, R24.1, U1.38 (PA15)
/STM32/INT1_ACC: U1.15 (PA7); also elsewhere on the board
/STM32/INT2_ACC: U1.14 (PA6); also elsewhere on the board
/STM32/LD_ST1: D1.2 (A), U1.2 (PC13)
/STM32/LD_ST2: D2.2 (A), U1.3 (PC14)
/STM32/LD_ST3: D3.2 (A), U1.4 (PC15)
/STM32/LIDAR_M_CTR: U1.32 (PA10); also elsewhere on the board
/STM32/LIDAR_TX: U1.11 (PA3); also elsewhere on the board
/STM32/NRST: C22.2, J1.12 (~RST), U1.7 (PG10)
/STM32/RX_SWD: J1.13 (VCP_RX), U1.40 (PC11)
/STM32/SCL: U1.46 (PB8); also elsewhere on the board
/STM32/SDA: U1.47 (PB9); also elsewhere on the board
/STM32/SWCLK: J1.6 (JCLK/SWCLK), U1.37 (PA14)
/STM32/SWDIO: J1.4 (JTMS/SWDIO), U1.36 (PA13)
/STM32/SWO: J1.8 (JTDO/SWO), U1.41 (PB3)
/STM32/TX_SWD: J1.14 (VCP_TX), U1.39 (PC10)
GND: C1.1, C2.2, C3.1, C5.1, C6.1, C7.1, C8.1, C9.1, C10.1, C11.1, C22.1, C35.2, J1.5 (GND), J1.7 (GND), J1.11 (GNDDetect), R7.2, R8.2, R9.2, SW2.2, U1.49 (VSS), Y1.2, Y1.4; also elsewhere on the board
unnamed: C1.2, R1.1, Y1.1
unnamed: D1.1 (K), R7.1
unnamed: D2.1 (K), R8.1
unnamed: D3.1 (K), R9.1
unnamed: R24.2, R25.1, SW2.1
unnamed: C2.1, U1.5 (PF0), Y1.3
unnamed: R1.2, U1.6 (PF1)

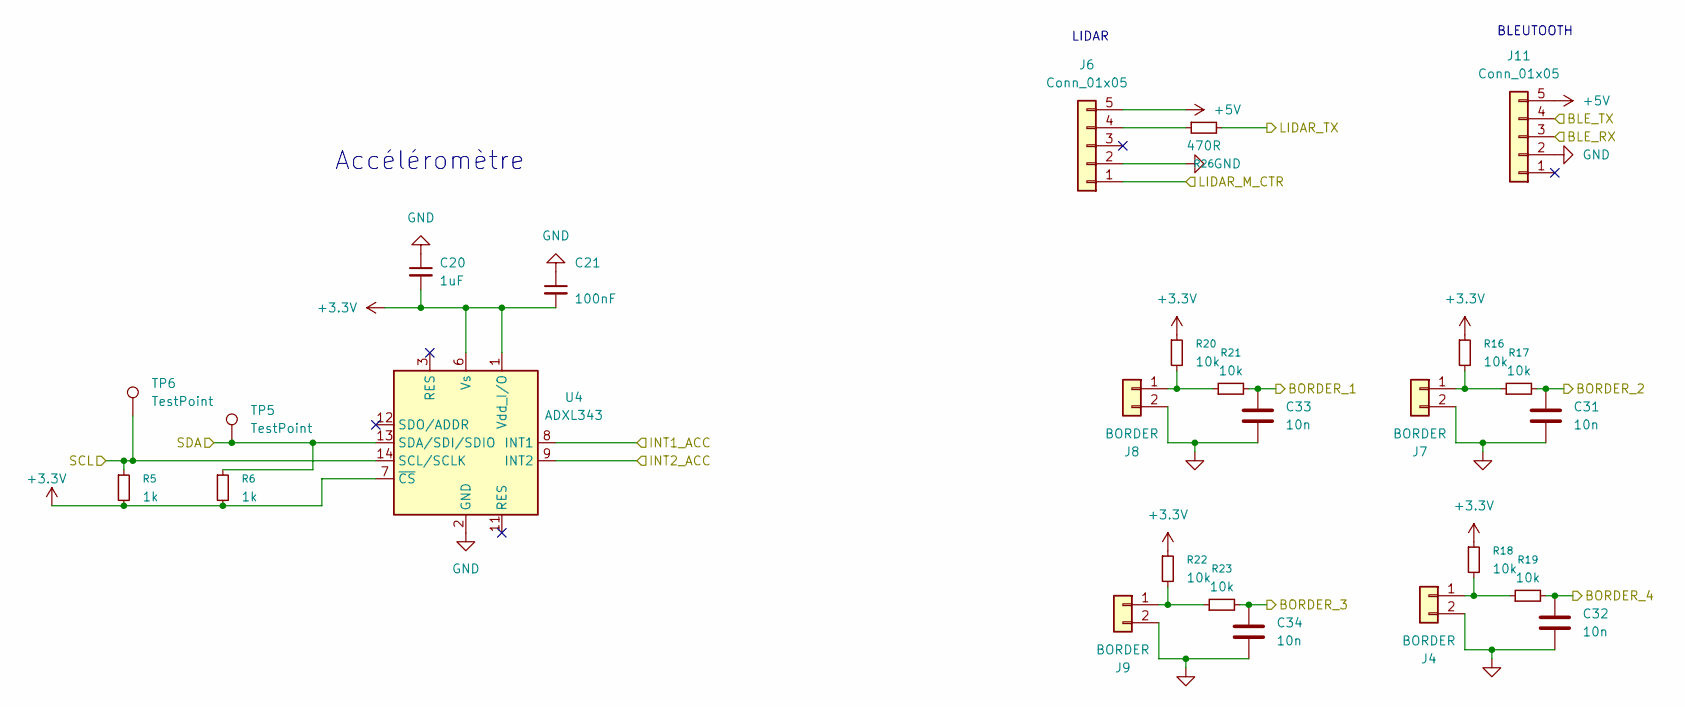
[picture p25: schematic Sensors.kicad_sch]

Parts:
C20: 1uF; C_0402_1005Metric
C21: 100nF; C_0402_1005Metric
C31, C32, C33, C34: 10n; C_0402_1005Metric
J4, J7, J8, J9: BORDER; JST_XH_S2B-XH-A_1x02_P2.50mm_Horizontal
J6: Conn_01x05; JST_XH_S5B-XH-A_1x05_P2.50mm_Horizontal; MPN YDLIDAR X2
J11: Conn_01x05; JST_XH_S5B-XH-A_1x05_P2.50mm_Horizontal
R5, R6: 1k; R_0402_1005Metric
R16, R17, R18, R19, R20, R21, R22, R23: 10k; R_0402_1005Metric
R26: 470R; R_0402_1005Metric
TP5, TP6: TestPoint; TestPoint_Pad_D1.0mm
U4: ADXL343; LGA-14_3x5mm_P0.8mm_LayoutBorder1x6y; MPN ADXL343BCCZ-RL

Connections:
+3.3V: C20.2, C21.2, R5.2, R6.2, R16.1, R18.1, R20.1, R22.1, U4.1 (Vdd_I/O), U4.6 (Vs), U4.7 (~CS); also elsewhere on the board
+5V: J6.5, J11.5; also elsewhere on the board
/STM32/BLE_RX: J11.3; also elsewhere on the board
/STM32/BLE_TX: J11.4; also elsewhere on the board
/STM32/BORDER_1: C33.1, R21.2; also elsewhere on the board
/STM32/BORDER_2: C31.1, R17.2; also elsewhere on the board
/STM32/BORDER_3: C34.1, R23.2; also elsewhere on the board
/STM32/BORDER_4: C32.1, R19.2; also elsewhere on the board
/STM32/INT1_ACC: U4.8 (INT1); also elsewhere on the board
/STM32/INT2_ACC: U4.9 (INT2); also elsewhere on the board
/STM32/LIDAR_M_CTR: J6.1; also elsewhere on the board
/STM32/LIDAR_TX: R26.2; also elsewhere on the board
/STM32/SCL: R5.1, TP6.1, U4.14 (SCL/SCLK); also elsewhere on the board
/STM32/SDA: R6.1, TP5.1, U4.13 (SDA/SDI/SDIO); also elsewhere on the board
GND: C20.1, C21.1, C31.2, C32.2, C33.2, C34.2, J4.2, J6.2, J7.2, J8.2, J9.2, J11.2, U4.2 (GND), U4.4 (GND), U4.5 (GND); also elsewhere on the board
unnamed: J4.1, R18.2, R19.1
unnamed: J6.4, R26.1
unnamed: J7.1, R16.2, R17.1
unnamed: J8.1, R20.2, R21.1
unnamed: J9.1, R22.2, R23.1

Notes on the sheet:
Accéléromètre
BLEUTOOTH
LIDAR

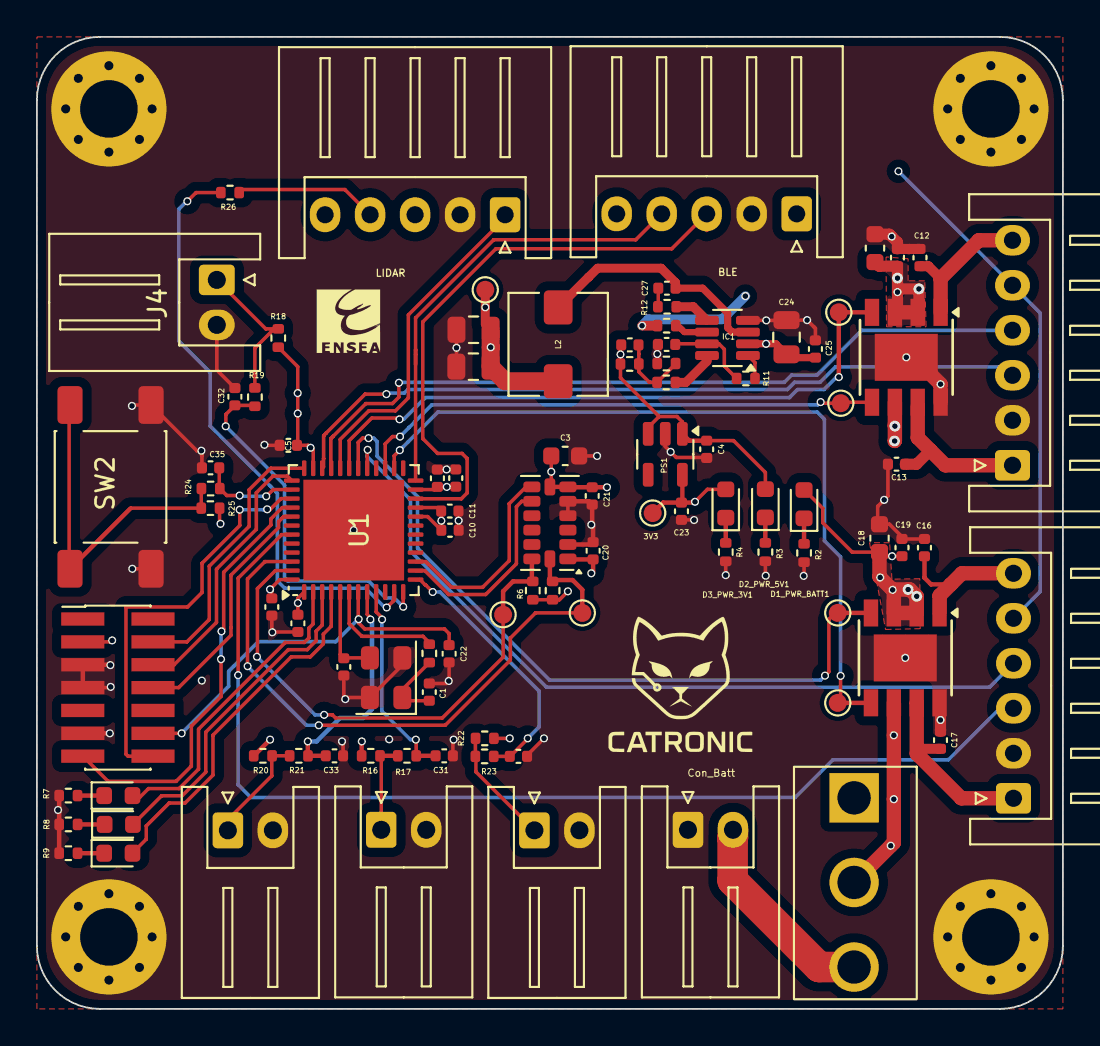
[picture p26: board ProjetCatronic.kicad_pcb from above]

Board: 4 copper layers, 57.0 x 54.0 mm, 99 parts (0 on the bottom side), 62 nets.

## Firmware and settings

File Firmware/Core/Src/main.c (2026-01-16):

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
/* Includes ------------------------------------------------------------------*/
#include "main.h"
#include "cmsis_os.h"
#include "dma.h"
#include "i2c.h"
#include "tim.h"
#include "usart.h"
#include "gpio.h"

/* USER CODE BEGIN Includes */
#include "MoteurPWM.h"
#include "drv_bt.h"
#include "ADXL343_driver.h"
#include "driver_LIDAR.h"
#include "border_sensors.h"
#include "robot_logic.h"
#include <stdio.h>
/* USER CODE END Includes */


/* USER CODE BEGIN PV */
Moteur_HandleTypeDef moteurD;
Moteur_HandleTypeDef moteurG;
h_Robot hrob;

SemaphoreHandle_t mutexSensors;

uint8_t lidar_dma_buffer[64]; // Buffer circulaire pour le DMA
h_YLIDARX2_t hlidar;          // Structure de contrôle LIDAR
/* USER CODE END PV */

void SystemClock_Config(void);
void MX_FREERTOS_Init(void);
/* USER CODE BEGIN 0 */
int __io_putchar(int ch)
{
	HAL_UART_Transmit(&huart4, (uint8_t*)&ch, 1, HAL_MAX_DELAY);
	return ch;
}

/* USER CODE END 0 */

/**
 * @brief  The application entry point.
 * @retval int
 */
int main(void)
{

	/* MCU Configuration--------------------------------------------------------*/

	/* Reset of all peripherals, Initializes the Flash interface and the Systick. */
	HAL_Init();

	/* Configure the system clock */
	SystemClock_Config();

	/* Initialize all configured peripherals */
	MX_GPIO_Init();
	MX_DMA_Init();
	MX_I2C1_Init();
	MX_TIM3_Init();
	MX_TIM4_Init();
	MX_TIM1_Init();
	MX_UART4_Init();
	MX_USART2_UART_Init();
	MX_USART3_UART_Init();
	MX_USART1_UART_Init();
	MX_TIM2_Init();
	/* USER CODE BEGIN 2 */

	//Initialisation du Bluetooth
	BT_Init();
	BT_SendString("BLE Ready\r\n");

	YLIDAR_Init(&hlidar);
	HAL_UART_Receive_DMA(&huart2, lidar_dma_buffer, sizeof(lidar_dma_buffer));// Démarre la réception DMA en mode circulaire
	HAL_GPIO_WritePin(GPIOA, GPIO_PIN_10, GPIO_PIN_RESET);

	Moteur_init(&moteurD, &htim1, TIM_CHANNEL_1);
	Moteur_init(&moteurG, &htim1, TIM_CHANNEL_2);

	Robot_Init(&hrob, &moteurD, &moteurG);
	printf("Robot Init OK\r\n");

	mutexSensors = xSemaphoreCreateMutex();
	if (mutexSensors == NULL)
	{
		printf("Erreur Mutex !\r\n");
		while(1);
	}
	//TEST tasks
	xTaskCreate(BluetoothTask, "BT", 128, NULL, 5, NULL);
	xTaskCreate(ShockTask,     "Shock", 128, NULL, 4, NULL);
	xTaskCreate(BorderTask,    "Border", 128, NULL, 3, NULL);
	xTaskCreate(RobotModeTask, "Mode", 128, NULL, 2, NULL);

	/* USER CODE END 2 */

	/* Init scheduler */
	osKernelInitialize();

	/* Call init function for freertos objects (in cmsis_os2.c) */
	MX_FREERTOS_Init();

	/* Start scheduler */
	osKernelStart();

	/* We should never get here as control is now taken by the scheduler */

	/* Infinite loop */
	/* USER CODE BEGIN WHILE */
	vTaskStartScheduler();
	printf("Taches FreeRTOS creees.\r\n");
	while (1)
	{

		/* USER CODE END WHILE */

		/* USER CODE BEGIN 3 */
	}
	/* USER CODE END 3 */
}

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
/* USER CODE BEGIN 4 */
void HAL_UART_RxHalfCpltCallback(UART_HandleTypeDef *huart) {
	if (huart->Instance == USART2)
		YLIDAR_PushBytes(lidar_dma_buffer, 32);
}

void HAL_UART_RxCpltCallback(UART_HandleTypeDef *huart) {
	if (huart->Instance == USART3) { // Bluetooth
		BT_UART_RxCpltCallback(BT_rxByte);
	}
	if (huart->Instance == USART2)
		YLIDAR_PushBytes(lidar_dma_buffer + 32, 32);
}
/* USER CODE END 4 */
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


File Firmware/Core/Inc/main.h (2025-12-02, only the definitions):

#define LED_ST1_Pin GPIO_PIN_13
#define LED_ST1_GPIO_Port GPIOC
#define LED_ST2_Pin GPIO_PIN_14
#define LED_ST2_GPIO_Port GPIOC
#define LED_ST3_Pin GPIO_PIN_15
#define LED_ST3_GPIO_Port GPIOC
#define BORDER_1_Pin GPIO_PIN_0
#define BORDER_1_GPIO_Port GPIOA
#define BORDER_2_Pin GPIO_PIN_1
#define BORDER_2_GPIO_Port GPIOA
#define LIDAR_TX_Pin GPIO_PIN_2
#define LIDAR_TX_GPIO_Port GPIOA
#define LIDAR_RX_Pin GPIO_PIN_3
#define LIDAR_RX_GPIO_Port GPIOA
#define BORDER_4_Pin GPIO_PIN_4
#define BORDER_4_GPIO_Port GPIOA
#define BORDER_3_Pin GPIO_PIN_5
#define BORDER_3_GPIO_Port GPIOA
#define INT2_ACC_Pin GPIO_PIN_6
#define INT2_ACC_GPIO_Port GPIOA
#define INT1_ACC_Pin GPIO_PIN_7
#define INT1_ACC_GPIO_Port GPIOA
#define BLE_TX_Pin GPIO_PIN_10
#define BLE_TX_GPIO_Port GPIOB
#define BLE_RX_Pin GPIO_PIN_11
#define BLE_RX_GPIO_Port GPIOB
#define REV2_Pin GPIO_PIN_13
#define REV2_GPIO_Port GPIOB
#define REV1_Pin GPIO_PIN_14
#define REV1_GPIO_Port GPIOB
#define ENCOD_B2_Pin GPIO_PIN_6
#define ENCOD_B2_GPIO_Port GPIOC
#define FWD2_Pin GPIO_PIN_8
#define FWD2_GPIO_Port GPIOA
#define FWD1_Pin GPIO_PIN_9
#define FWD1_GPIO_Port GPIOA
#define ENCOD_B1_Pin GPIO_PIN_11
#define ENCOD_B1_GPIO_Port GPIOA
#define ENCOD_A1_Pin GPIO_PIN_12
#define ENCOD_A1_GPIO_Port GPIOA
#define SWDIO_Pin GPIO_PIN_13
#define SWDIO_GPIO_Port GPIOA
#define SWCLK_Pin GPIO_PIN_14
#define SWCLK_GPIO_Port GPIOA
#define SWD_TX_Pin GPIO_PIN_10
#define SWD_TX_GPIO_Port GPIOC
#define SWD_RX_Pin GPIO_PIN_11
#define SWD_RX_GPIO_Port GPIOC
#define SWO_Pin GPIO_PIN_3
#define SWO_GPIO_Port GPIOB
#define ENCOD_A2_Pin GPIO_PIN_5
#define ENCOD_A2_GPIO_Port GPIOB
#define SCL_Pin GPIO_PIN_8
#define SCL_GPIO_Port GPIOB
#define SDA_Pin GPIO_PIN_9
#define SDA_GPIO_Port GPIOB

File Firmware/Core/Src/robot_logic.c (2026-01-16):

#include "robot_logic.h"
#include "border_sensors.h"
#include "drv_bt.h"
#include "ADXL343_driver.h"
#include "driver_LIDAR.h"
#include "MoteurPWM.h"

#include "FreeRTOS.h"
#include "task.h"
#include "semphr.h"
#include <string.h>
#include <stdio.h>
#include "main.h"

extern SemaphoreHandle_t mutexSensors;
extern I2C_HandleTypeDef hi2c1;
extern h_Robot hrob;
extern h_YLIDARX2_t hlidar;
extern Moteur_HandleTypeDef moteurD;
extern Moteur_HandleTypeDef moteurG;

uint8_t shock_detected = 0;
uint8_t border_active = 0;
BorderDirection_t border_dir = BORDER_NONE;
RobotMode_t robot_mode = ROBOT_STOP;


void BorderTask(void *argument)
{
	printf("BorderTask STARTED\r\n");

	for (;;)
	{
		BorderDirection_t d = BorderSensors_GetDirection();

		xSemaphoreTake(mutexSensors, portMAX_DELAY);
		border_dir = d;
		border_active = (d != BORDER_NONE);
		xSemaphoreGive(mutexSensors);

		if (d != BORDER_NONE)
			printf("BORDER DETECTED: %d\r\n", d);

		vTaskDelay(pdMS_TO_TICKS(100));
	}
}



void ShockTask(void *argument)
{
	HAL_StatusTypeDef ret;

	ret = ADXL343_Init(&hi2c1);
	ret = ADXL343_ConfigShock(&hi2c1, 0.5f, 50.0f);

	for (;;)
	{
		if (ADXL343_CheckShock(&hi2c1))
		{
			printf("choc detecte\r\n");
			xSemaphoreTake(mutexSensors, portMAX_DELAY);
			if (robot_mode != ROBOT_STOP)
			{
				shock_detected = 1;

				if (robot_mode == ROBOT_MODE_CHAT)
				{
					robot_mode = ROBOT_MODE_SOURIS;
					BT_SendString("Mode auto -> SOURIS\r\n");
					printf("Mode auto -> SOURIS\r\n");
				}
				else if (robot_mode == ROBOT_MODE_SOURIS)
				{
					robot_mode = ROBOT_MODE_CHAT;
					BT_SendString("Mode auto -> CHAT\r\n");
					printf("Mode auto -> CHAT\r\n");
				}
			}

			xSemaphoreGive(mutexSensors);

			vTaskDelay(pdMS_TO_TICKS(300)); // anti-rebond
		}

		vTaskDelay(pdMS_TO_TICKS(50));
	}
}


void BluetoothTask(void *argument)
{
	for (;;)
	{
		if (BT_cmdReady)
		{
			BT_cmdReady = 0;

			xSemaphoreTake(mutexSensors, portMAX_DELAY);

			if (strcmp(BT_cmd, "STOP") == 0)
			{
				robot_mode = ROBOT_STOP;
				BT_SendString("Robot STOP\r\n");
				printf("Robot STOP\r\n");
			}
			else if (strcmp(BT_cmd, "START") == 0)
			{
				robot_mode = ROBOT_MODE_CHAT;
				BT_SendString("Robot START -> CHAT\r\n");
				printf("Robot START -> CHAT\r\n");
			}
			else if (strcmp(BT_cmd, "CHAT") == 0)
			{
				robot_mode = ROBOT_MODE_CHAT;
				BT_SendString("Mode -> CHAT\r\n");
				printf("Mode -> CHAT\r\n");
			}
			else if (strcmp(BT_cmd, "SOURIS") == 0)
			{
				robot_mode = ROBOT_MODE_SOURIS;
				BT_SendString("Mode -> SOURIS\r\n");
				printf("Mode -> SOURIS\r\n");
			}
			else if (strcmp(BT_cmd, "STATUS") == 0)
			{
				if (robot_mode == ROBOT_MODE_CHAT)
					BT_SendString("STATUS: CHAT\r\n");

				else if (robot_mode == ROBOT_MODE_SOURIS)
					BT_SendString("STATUS: SOURIS\r\n");

				else
					BT_SendString("STATUS: STOP\r\n");
			}
			else
			{
				BT_SendString("Commande inconnue\r\n");
			}

			memset(BT_cmd, 0, sizeof(BT_cmd));
			xSemaphoreGive(mutexSensors);
		}

		vTaskDelay(pdMS_TO_TICKS(20));
	}
}


void RobotModeTask(void *argument)
{
	for (;;)
	{
		// 1. Traiter les données brutes du LIDAR
		YLIDAR_Process(&hlidar);

		RobotMode_t mode;
		BorderDirection_t d;
		uint8_t b_active;

		xSemaphoreTake(mutexSensors, portMAX_DELAY);
		mode = robot_mode;
		d = border_dir;
		b_active = border_active;
		xSemaphoreGive(mutexSensors);

		if (mode == ROBOT_STOP)
		{
			Robot_Stop(&hrob);
		}
		else if (b_active)
		{
			// Sécurité bordure PRIORITAIRE
			if (d == BORDER_AVANT_GAUCHE || d == BORDER_AVANT_DROITE)
			{
				Robot_Recule(&hrob, 15);
				vTaskDelay(pdMS_TO_TICKS(600));
				Moteur_setSpeed(&moteurG, 5);
				vTaskDelay(pdMS_TO_TICKS(700));
				Robot_Stop(&hrob);
				vTaskDelay(pdMS_TO_TICKS(100));



			}
			else if (d == BORDER_ARRIERE_GAUCHE || d == BORDER_ARRIERE_DROITE)
			{
				Robot_Start(&hrob, 15);
				vTaskDelay(pdMS_TO_TICKS(600));
				Moteur_setSpeed(&moteurG, 5);
				vTaskDelay(pdMS_TO_TICKS(700));
				Robot_Stop(&hrob);
				vTaskDelay(pdMS_TO_TICKS(100));
			}
		}
		else if (mode == ROBOT_MODE_CHAT || mode == ROBOT_MODE_SOURIS)
		{
			// --- SOLUTION DÉTECTION OBSTACLE ---
			float min_dist = 2000.0f;
			float target_angle = 0.0f;
			int obstacle_found = 0;

			// On parcourt les derniers points échantillonnés
			for (int i = 0; i < hlidar.sample_quantity; i++) {
				// On ignore les distances à 0 (erreurs) et trop lointaines
				if (hlidar.points[i].distance > 50 && hlidar.points[i].distance < 1000) {
					if (hlidar.points[i].distance < min_dist) {
						min_dist = hlidar.points[i].distance;
						target_angle = hlidar.points[i].angle;
						obstacle_found = 1;
					}
				}
			}

			if (obstacle_found) {
				printf("Cible: Dist=%dmm, Angle=%.1f\r\n", (int)min_dist, target_angle);

				if (mode == ROBOT_MODE_CHAT) {
					// Mode CHAT : On fonce vers l'obstacle (entre -20° et 20°)
					if (target_angle > 340 || target_angle < 20) Robot_Start(&hrob, 15);
					else if (target_angle >= 20 && target_angle < 180) Moteur_setSpeed(&moteurG, 10); // Tourne à droite
					else Moteur_setSpeed(&moteurD, 10); // Tourne à gauche
				}
				else {
					// Mode SOURIS : On fuit si l'obstacle est trop proche (< 30cm)
					if (min_dist < 300) Robot_Recule(&hrob, 15);
					else Robot_Start(&hrob, 15);
				}
			} else {
				Robot_Stop(&hrob); // Rien en vue
			}
		}
		vTaskDelay(pdMS_TO_TICKS(50));
	}
}

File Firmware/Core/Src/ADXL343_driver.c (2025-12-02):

#include "ADXL343_driver.h"
#include <math.h>


static HAL_StatusTypeDef adxl_write(I2C_HandleTypeDef *hi2c,uint8_t reg, uint8_t value)
{
	return HAL_I2C_Mem_Write(hi2c,
			ADXL343_ADDR,
			reg,
			I2C_MEMADD_SIZE_8BIT,
			&value,
			1,
			HAL_MAX_DELAY);
}

static HAL_StatusTypeDef adxl_read(I2C_HandleTypeDef *hi2c,uint8_t reg, uint8_t *value)
{
	return HAL_I2C_Mem_Read(hi2c,
			ADXL343_ADDR,
			reg,
			I2C_MEMADD_SIZE_8BIT,
			value,
			1,
			HAL_MAX_DELAY);
}

//initialisation

uint8_t ADXL343_Init(I2C_HandleTypeDef *hi2c)
{
	uint8_t devid = 0;

	// Vérifier l'ID du capteur
	if (adxl_read(hi2c, ADXL_DEVID, &devid) != HAL_OK || devid != 0xE5)
		return 0;
	// 100 Hz
	if (adxl_write(hi2c, ADXL_BW_RATE, ADXL_DATA_RATE_100HZ) != HAL_OK)
		return 0;
	// FULL RES + ±2g
	uint8_t data_format = ADXL_FULL_RES | ADXL_RANGE_2G;
	if (adxl_write(hi2c, ADXL_DATA_FORMAT, data_format) != HAL_OK)
		return 0;
	// Mode mesure
	if (adxl_write(hi2c, ADXL_POWER_CTL, ADXL_POWER_MEASURE) != HAL_OK)
		return 0;

	return 1;
}

//lecture des axes, de lacceleration et de la difference d'acceleration

uint8_t ADXL343_ReadAxes(I2C_HandleTypeDef *hi2c, adxl343_axes_t *axes)
{
	uint8_t buf[6];

	if (HAL_I2C_Mem_Read(hi2c, ADXL343_ADDR, ADXL_DATAX0,I2C_MEMADD_SIZE_8BIT, buf, 6, HAL_MAX_DELAY) != HAL_OK)
		return 0;

	axes->x = (int16_t)((buf[1] << 8) | buf[0]);
	axes->y = (int16_t)((buf[3] << 8) | buf[2]);
	axes->z = (int16_t)((buf[5] << 8) | buf[4]);

	return 1;
}

//detection de choc

HAL_StatusTypeDef ADXL343_ConfigShock(I2C_HandleTypeDef *hi2c,float thresh_g,float dur_ms)
{
	HAL_StatusTypeDef ret;
	//choc
	const float lsb_g = 0.0625f;
	uint8_t thresh = (uint8_t)(thresh_g / lsb_g);
	if (thresh == 0) thresh = 1;

	ret = adxl_write(hi2c, ADXL_THRESH_TAP, thresh);
	if (ret != HAL_OK) return ret;
	//durée
	const float lsb_ms = 0.625f;
	uint8_t dur = (uint8_t)(dur_ms / lsb_ms);
	if (dur == 0) dur = 1;

	ret = adxl_write(hi2c,  ADXL_DUR, dur);
	if (ret != HAL_OK) return ret;

	//activation des 3 axes pour la detection
	ret = adxl_write(hi2c,  ADXL_TAP_AXES, 0x07); // X,Y,Z
	if (ret != HAL_OK) return ret;

	//enable l'interruption de l'adx
	uint8_t int_enable = ADXL_INT_DATA_READY | ADXL_INT_SINGLE_TAP;
	ret = adxl_write(hi2c, ADXL_INT_ENABLE, int_enable);
	if (ret != HAL_OK) return ret;
	uint8_t int_map = 0x40;
	ret = adxl_write(hi2c, ADXL_INT_MAP, int_map);
	if (ret != HAL_OK) return ret;

	return HAL_OK;
}

//vérifier le choc

uint8_t ADXL343_CheckShock(I2C_HandleTypeDef *hi2c)
{
	uint8_t src = 0;
	adxl_read(hi2c, ADXL_INT_SOURCE, &src);

	return (src & ADXL_INT_SINGLE_TAP) ? 1 : 0;
}

//calculer l'acceleration
float ADXL343_ComputeTotalG(float xg, float yg, float zg)
{
	return sqrtf((xg * xg) + (yg * yg) + (zg * zg));
}

//afficher les resultats sur teraterm
void ADXL343_PrintAxes(I2C_HandleTypeDef *hi2c)
{
	static float prevA = 1.0f;  // mémorise l'accélération précédente

	adxl343_axes_t axes;

	if (!ADXL343_ReadAxes(hi2c, &axes)) {
		printf("Erreur lecture XYZ\r\n");
		return;
	}

	float xg = ADXL343_RawTo_g(axes.x);
	float yg = ADXL343_RawTo_g(axes.y);
	float zg = ADXL343_RawTo_g(axes.z);

	float Atot = ADXL343_ComputeTotalG(xg, yg, zg);
	float deltaA = fabsf(Atot - prevA);

	prevA = Atot;  // mise à jour pour prochaine itération

	printf("X=%.3f g  Y=%.3f g  Z=%.3f g  |  A=%.3f g  |  dA=%.3f g\r\n",
			xg, yg, zg, Atot, deltaA);
}

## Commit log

2025-09-22 first commit from this laptop.
    [Actionneurs.kicad_sch, Alimentation.kicad_sch, STM32.kicad_sch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]
2025-09-24 Update KiCad schematics
    [Actionneurs.kicad_sch, STM32.kicad_sch, Sensors.kicad_sch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]
2025-09-24 Updated project
    [Actionneurs.kicad_sch, Alimentation.kicad_sch, STM32.kicad_sch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]
2025-09-24 Clean repo: ignore KiCad backup/autosave files
2025-10-01 Replaced old project folder with ProjetX
    [74404052010_Download_STP_WE-LQS-5020_rev1.stp, Actionneurs.kicad_sch, Alimentation.kicad_sch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]
2025-10-01 Renamed folder to Projet_Robot_Autonome
    [74404052010_Download_STP_WE-LQS-5020_rev1.stp, Actionneurs.kicad_sch, Alimentation.kicad_sch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]
2025-10-06 Updated KiCad project files
    [Actionneurs.kicad_sch, Alimentation.kicad_sch, ProjetX.kicad_pcb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]
2025-10-13 Clean repository before re-upload
    [1000-series_spdt_.psm, 1101M2S3CQE2.stp, 74404052010_Download_STP_WE-LQS-5020_rev1.stp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]
2025-10-13 Rename project folder to Project_Catronic
    [1000-series_spdt_.psm, 1101M2S3CQE2.stp, 74404052010_Download_STP_WE-LQS-5020_rev1.stp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]
2025-10-13 Update KiCad project with latest schematic and PCB edits
    [ProjetX.kicad_pcb, ProjetX.kicad_sch]
2025-10-13 Update KiCad project files (Project_Catronic)
    [ProjetX-B_Cu.gbr, ProjetX-B_Mask.gbr, ProjetX-B_Paste.gbr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]
2025-12-02 Enhance README with system architecture and power info
    Added system architecture and power regulation details to README.
2025-12-02 Driver Moteur
2025-12-03 Driver lidar +bleutooth
2026-01-15 avancement sur la tache de lidar
2026-01-16 Enhance README with new tests and visualizations
    Added new tests for Bluetooth communication and LIDAR functionality, including visualizations and descriptions. Updated existing sections with images and clarified test descriptions.
2026-01-16 Enhance README with project structure and software details
    Updated the edge detection section to specify the number of edge sensors and added a project structure section along with software architecture details, including diagrams and main source files.
2026-01-16 add test motor
    Corrected formatting and added an image for motor test.
2026-01-16 Update test section for motor control and adjustments
    Clarified the PWM control validation and adjustments for motor speeds.

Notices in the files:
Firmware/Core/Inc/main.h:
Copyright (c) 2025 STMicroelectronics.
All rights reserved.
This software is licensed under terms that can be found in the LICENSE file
